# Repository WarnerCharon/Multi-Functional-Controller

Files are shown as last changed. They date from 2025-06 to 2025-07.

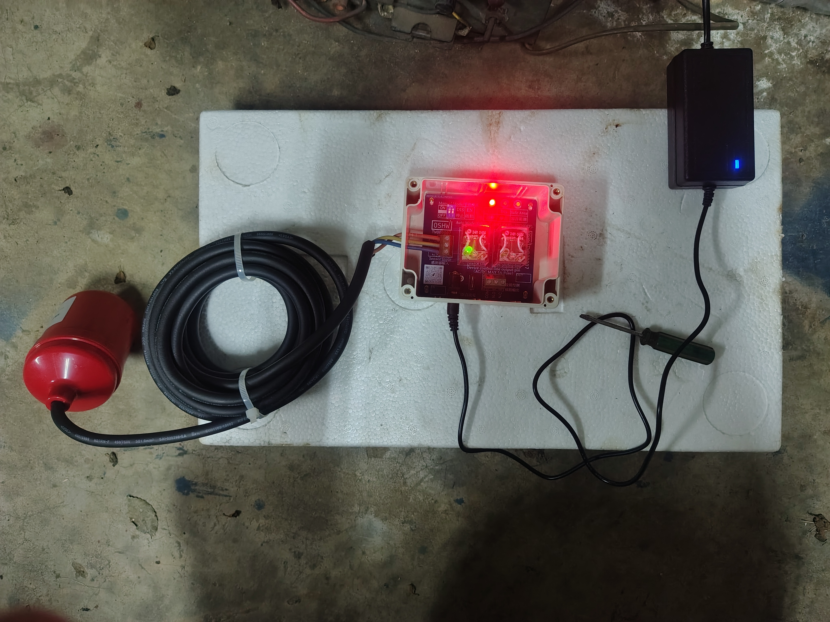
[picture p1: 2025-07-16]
Technical Documents/展示圖_2.jpg

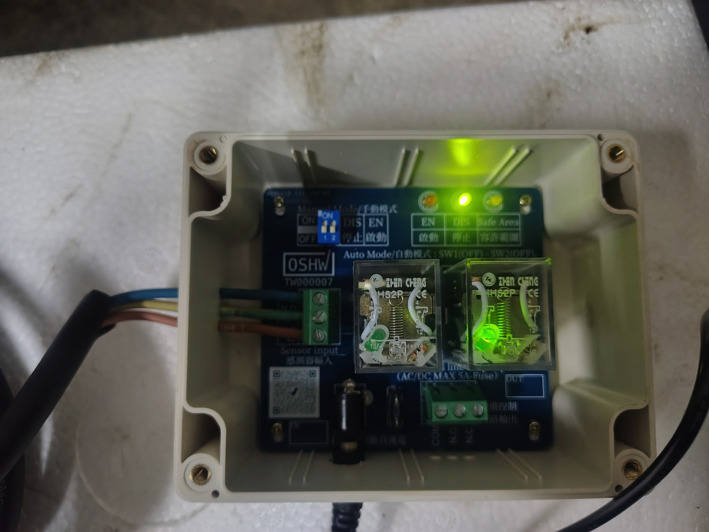
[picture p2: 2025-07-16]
Technical Documents/展示圖_1.jpg

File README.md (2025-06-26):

certification-mark-TW000007-stacked

EN:
The Multi-Functional-Controller is an open-source industrial-grade mechanical logic controller designed to handle multiple control scenarios such as liquid level regulation, pneumatic pressure stabilization, and temperature management. It utilizes reliable mechanical relay logic and discrete input signals to achieve three-point control: Start, Maintain, and Stop — enabling stable and efficient actuation of pumps, compressors, heaters, and fans. The controller incorporates built-in anti-chatter logic to prevent unnecessary rapid switching caused by signal fluctuations, thereby extending equipment life.

Designed for plug-and-play operation, the controller requires no software programming, making installation and commissioning simple for industrial operators. Control setpoints are defined via external sensors or float switches wired directly to its input terminals. The output controls motorized equipment directly, supporting both single-phase and three-phase loads. An intuitive LED status display provides real-time visual feedback of the system state.

The open hardware release includes complete schematics, PCB layouts, electrical assembly diagram, detailed component BOM, and connection diagrams. The operation logic are fully documented and provided under open-source licenses. Users can freely build, modify, adapt, and integrate the design into custom automation solutions.

This controller is ideal for industrial water treatment systems, HVAC units, air compressors, and process control where reliable, simple, and low-cost control is needed without the complexity of PLC programming. Its open-source nature allows educational institutions, OEM manufacturers, system integrators, and hobbyists to adopt, learn, and further develop derivative control systems while contributing back to the open hardware community.

This controller project (Multi-Functional-Controller) fully complies with international open source hardware standards and is officially certified by the Open Source Hardware Association (OSHWA). All design archives and source codes are released under the following licenses:

Hardware design: OSHWA、CERN OHL-W v2.0

Control logic: Apache License 2.0

Document content: CC-BY 4.0

OSHWA Certification ID: TW000007
https://certification.oshwa.org/tw000007.html

👉 GitHub original code and design access: https://github.com/WarnerCharon/Multi-Functional-Controller

Multi-Functional-Controller  © 2025/6 by TSAI, AN-HSIANG is licensed under CC BY 4.0. To view a copy of this license, visit https://creativecommons.org/licenses/by/4.0/

TW:
多功能控制器是一種開源工業級機械邏輯控制器，旨在處理多種控制場景，例如液位水平調節，氣動壓力穩定和溫度管理。它利用可靠的機械繼電器邏輯和離散輸入信號來實現三點控制：啟動，維護和停止 - 可以穩定，有效地致動泵，壓縮機，加熱器和風扇。控制器結合了內置的反塊狀邏輯，以防止信號波動引起的不必要的快速切換，從而延長設備壽命。

該控制器專為插件操作而設計，不需要軟件編程，使工業運營商的安裝和調試簡單。控制設定點是通過外部傳感器或直接連接到其輸入終端的浮子開關來定義的。輸出直接控制電動設備，支持單相和三相載荷。直觀的LED狀態顯示提供了系統狀態的實時視覺反饋。

開放的硬件版本包括完整的原理圖，PCB佈局，電氣組件圖，詳細的組件BOM和連接圖。操作邏輯已完全記錄並在開源許可下提供。用戶可以自由構建，修改，適應和集成設計到自定義自動化解決方案中。

該控制器非常適合工業水處理系統，HVAC單元，空氣壓縮機以及過程控制，而在沒有PLC編程的複雜性的情況下，需要可靠，簡單和低成本的控制。它的開源性質允許教育機構，OEM製造商，系統集成商和業餘愛好者採用，學習和進一步開發衍生性控制系統，同時又回到開放的硬件社區。

本控制器專案（Multi-Functional-Controller）完全符合國際開源硬體標準，並獲得開源硬體協會（OSHWA）的官方認證。所有設計檔案和原始碼均遵循以下許可證發布：

硬體設計：OSHWA、CERN OHL-W v2.0

控制邏輯：Apache License 2.0

文檔內容：CC-BY 4.0

OSHWA Certification ID: TW000007
https://certification.oshwa.org/tw000007.html

👉 GitHub 原始碼與設計存取：https://github.com/WarnerCharon/Multi-Functional-Controller

Multi-Functional-Controller  © 2025/6 by TSAI, AN-HSIANG is licensed under CC BY 4.0. To view a copy of this license, visit https://creativecommons.org/licenses/by/4.0/

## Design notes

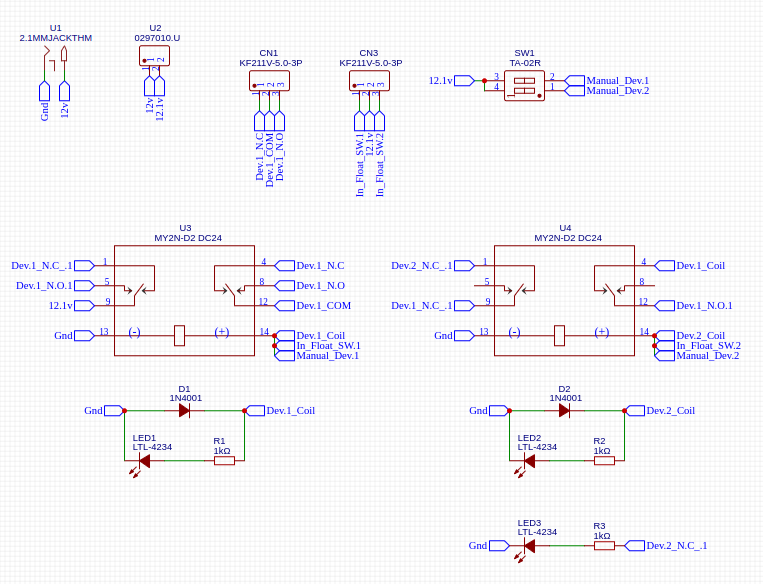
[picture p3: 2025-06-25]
hardware/Schematic.png

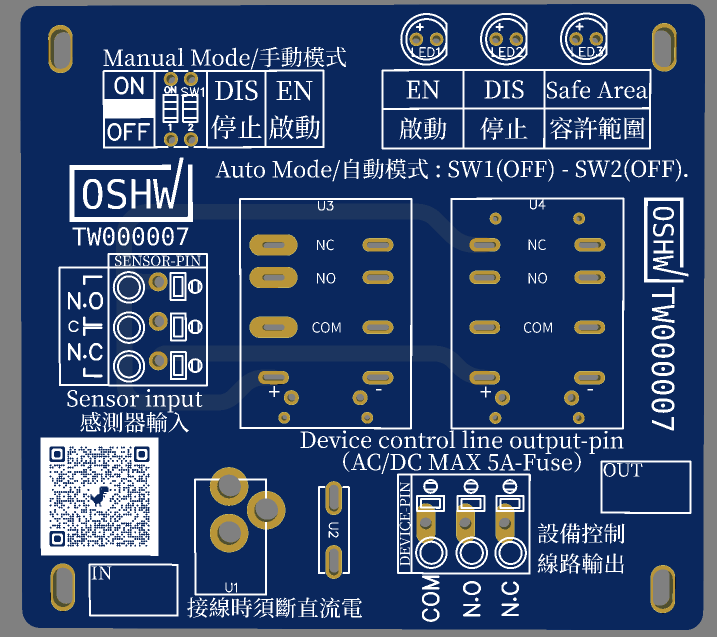
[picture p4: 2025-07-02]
Technical Documents/Photo/3D/top_n.png

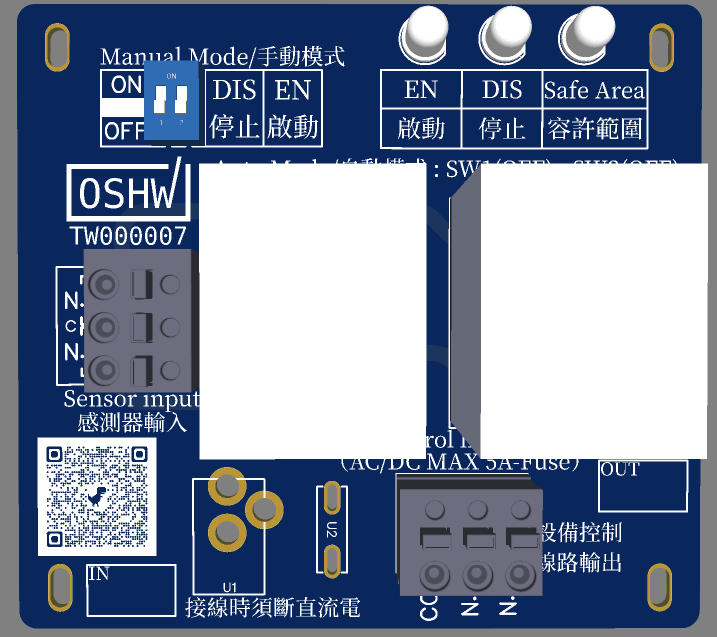
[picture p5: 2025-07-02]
Technical Documents/Photo/3D/top.png

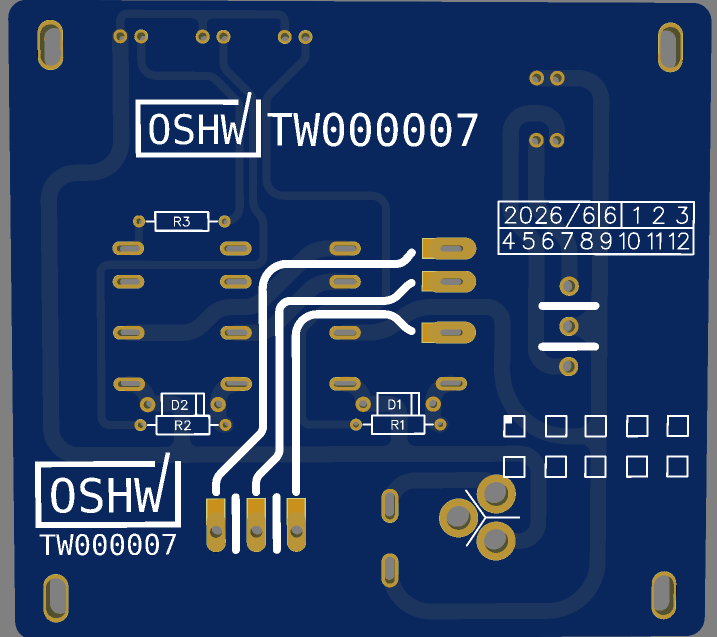
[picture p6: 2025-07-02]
Technical Documents/Photo/3D/button.png

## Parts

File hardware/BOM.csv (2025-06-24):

ID | Name | Designator | Footprint | Quantity
1 | 1N4001 | D1,D2 | DO-41_BD2.4-L4.7-P8.70-D0.9-RD | 2
2 | 1kΩ | R1,R2,R3 | RES-TH_BD2.3-L6.5-P10.50-D0.5 | 3
3 | KF211V-5.0-3P | DEVICE-PIN,SENSOR-PIN | CONN-TH_3P-P5.00_KF211V-5.0-3P | 2
4 | LTL-4234 | LED1,LED2,LED3 | LED-TH_BD5.0-P2.54-FD | 3
5 | TA-02R | SW1 | SW-TH_TA-02R | 1
6 | 2.1MMJACKTHM | U1 | PJ-102A | 1
7 | 0297010.U | U2 | FUSE-TH_0297010.WXNV | 1
8 | MY2N-D2 DC24 | U3,U4 | RELAY-TH_OMRON-MY2 | 2

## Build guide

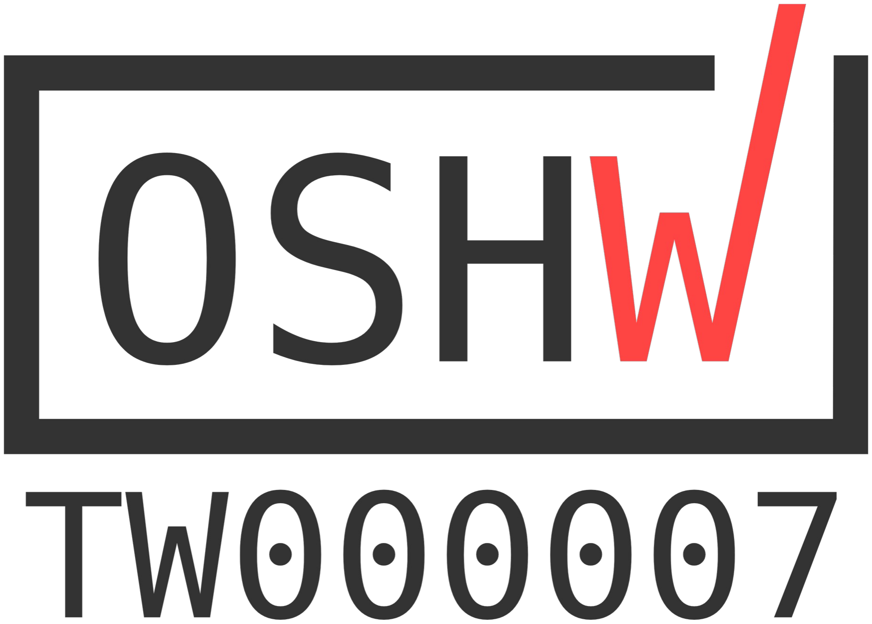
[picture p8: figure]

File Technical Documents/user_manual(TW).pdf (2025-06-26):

目次

TW000007

# 1. 產品概述

## 核心功能

- 高靈活性多功能控制器，採用機械接點設計，無電子故障風險，避免頻繁啟停，延長設備壽命， 適用於液體、氣體、溫度等多種物理量的控制。
- 成本效益高、免編程、安裝簡單，模組化設計使平均維修工時縮短 40%。
- 性價比高，適合中小型工程場域。

## 主要特色

- 三段式精確控制：啟動/停止/容許範圍邏輯
- 雙重操作模式：自動/手動切換
- 機械抖動消除技術：防止頻繁啟停
- 直觀狀態指示：LED 燈號顯示
- 工業級 PCB 材料：主控板採用 FR4 玻璃纖維基板，具備優異的耐腐蝕、耐高溫性能， 適用於嚴苛工業環境，提升產品壽命與安全性

## 典型應用

應用類型 | 控制對象 | 典型場景
液位控制 | 水泵、排水泵 | 水塔補水、污水處理
氣壓控制 | 空壓機、氣動系統 | 工廠供氣、氣動設備
溫度控制 | 加熱器、冷卻風扇 | 設備散熱、環境溫控

# 2. 安全須知

## ⚠️安裝前必讀

電氣安全
- 所有電氣作業必須在斷電狀態下進行
- 控制板輸入電壓規格（12V）
- 確認現場電壓符合設備規格（110V/220V AC）
- 必須安裝適當的接地保護
- 使用正確規格的保險絲（5A）
機械安全
- 避免感測器受到直接衝擊或振動
- 預留足夠的維護空間

環境要求

- 工作溫度：-10°C ~ 50°C
- 避免直接日曬、雨淋
- 遠離腐蝕性氣體環境

# 3. 技術規格

## 基本規格

項目 | 規格 | 備註
電源電壓 | 110V/220V AC ±10% 根據型號選擇
保險絲 | 5A | 兩種電壓通用
輸出通道 | 1 組獨立控制輸出 | 可控制單相/三相馬達
感測輸入 | 3 點式接點輸入 | N.O/N.C/COM
工作溫度 | -10°C ~ 50°C | 工業級元件
防護等級 | IP54 | 防塵防水濺
外形尺寸 | 240×180×95mm | 壁掛式安裝

## 輸入訊號特性 ＊

訊號穩定性要求 ＊
- 所有輸入皆為「接點觸發」，若輸入訊號波動過快（如氣壓快速變化），建議：
- 加裝繼電器延遲模組
- 增加濾波/去抖時間設定
- 確保感測器機構反應靈敏且無接觸不良
三段區間辨識清晰度 ＊
- 三點控制需有明確的「高／中／低」輸出狀態
- 若只有雙段訊號，將導致容許範圍判斷失效
- 若僅一段訊號（如單段限位），則無法達成本控制邏輯，建議改用其他控制器

## 術語定義

術語 | 英文縮寫 | 定義
常開接點 | N.O | 平時斷開，觸發時閉合
常閉接點 | N.C | 平時閉合，觸發時斷開
共同點 | COM | 接點共用端子
過載保護 | OL | 馬達過載保護裝置
繼電器 | KM1/KM2 | 控制馬達的繼電器模塊

# 4. 安裝指南

## 4.1 安裝準備

環境檢查清單
- 電源電壓確認（110V/220V）
- 安裝空間評估（預留維護空間）
- 環境條件檢查（溫度、濕度、腐蝕性）
工具準備
- 螺絲起子、數位電錶、絕緣膠帶
- 配線管材、接線端子、標籤紙

## 4.2 機械安裝 ＊

控制器安裝
1. 選擇乾燥、通風良好的位置
2. 使用 DIN 導軌或螺絲固定
3. 確保防護等級符合現場環境
感測器安裝
1. 液位感測器
- 安裝高度：距離液面 0.5-1.5 公尺
- 避免水流直接衝擊
- 確保浮球動作範圍無阻礙
2. 其他感測器
- 確保感測範圍無遮擋物
- 避免機械振動干擾
- 考慮環境與溫度影響

機構安裝與回復機制 使用於移動、限位、轉速等應用時，建議：
- 感測器安裝處需避開干擾源與機械擾動 ＊＊
- 感測件應能「自復原狀態」（如彈簧回復、磁性歸位） ＊＊

## 4.3 電氣接線

基本接線步驟
1. 斷電確認：確保所有電源已切斷
2. 主電源接線：L1、L2 端子接入 AC 電源
3. 感測器接線：按照 N.O、N.C、COM 標示接線
4. 負載接線：連接執行機構（馬達、泵浦等）- > (附錄 A. 感測器控制接線圖)
5. 保護接線：連接過載保護器和接地線
接線規範
- 線徑選擇：根據負載電流選擇適當線徑
- 接線牢固：確保端子螺絲緊固
- 標識清楚：所有線路必須標識
- 絕緣良好：接線完成後進行絕緣測試

## 4.4 測試驗證

系統檢查
1. 電源測試
- 控制班輸入電壓：12V
- 測量輸入電壓：110V/220V ±10%
- 確認保險絲規格正確
- 檢查指示燈是否正常點亮
2. 感測器測試
- 手動觸發感測器
- 觀察指示燈變化
- 測量接點阻抗
3. 執行機構測試
- 手動模式測試馬達動作
- 檢查過載保護功能
- 確認控制邏輯正確

# 5. 操作與應用

## 5.1 控制面板說明

指示燈狀態
指示燈 1 紅色 觸發動作（系統啟動）
指示燈 2 綠色 停止狀態（系統停止）
指示燈 3 黃色 容許範圍（正常等待）

手動操作開關

SW1 ON 系統停止
SW2 ON 手動強制啟動

## 5.2 操作模式

自動控制模式

- SW1 & SW2 設為 OFF
- 系統依感測器狀態自動運行
- 適用於正常運行狀態
手動控制模式
- SW1 設為 ON：強制停止
- SW2 設為 ON：強制啟動
- 適用於測試或緊急情況
混合控制模式
- 正常時自動控制
- 必要時手動介入
- 適用於需要彈性操作的場合

## 5.3 基本應用

液位控制系統
應用場景：家用、工業、循環用水、地下室排水、排污、清洗用水、綠化澆灌，等等…。 進水控制：低水位啟動→中水位（正常容許範圍）→高水位停止 排水控制：高水位啟動→中水位（正常容許範圍）→低水位停止

應用設定
功能 觸發接點 停止接點 共同點
進水 N.C | N.O | COM
排水 N.O | N.C | COM

## 5.4 延伸應用

氣壓控制系統
- 應用場景：空壓機、氣動設備壓力控制 、工廠供氣系統、儲氣桶壓力管理
- 控制對象：螺旋式空壓機(15HP)、工業用空壓機
- 感測要求：三段式壓力開關
溫度控制系統
- 控制對象：加熱器、冷卻風扇
- 感測要求：三段式溫控開關
- 控制邏輯：低溫啟動→適溫維持→高溫停止
特殊控制應用
- 高度/距離控制：需配合信號轉換器
- 轉速控制：適用於低精度間接控制
- 流量控制：需配合流量開關

# 6. 參數設定

## 6.1 物理量特性評估 ＆ 參數設定指南

參數調整可依現場情況優化，若動作過頻可擴大遲滯區間或增加抖動消除時間，若反應遲緩則反向調整。 響應時間分類
類型 | 變化時間 | 典型應用(須根據場景)
快速響應 | <5 秒 | 氣壓、液壓系統
中等響應 | 5-30 秒 | 小容量液位控制
慢速響應 | >30 秒 | 溫度、大容量液位

抖動消除時間設定（如有加裝繼電器延遲模組 ）
可根據應用類型（液位、氣壓、溫度、位置）調整抖動消除時間（如 2-60 秒），防止訊號雜訊造成頻繁 切換。
應用類型 | 建議時間 | 設定原則
液位控制 | 2-5 秒 | 根據液體流動速度
氣壓控制 | 3-8 秒 | 考慮氣體壓縮特性
溫度控制 | 30-60 秒 | 依據熱慣性調整

遲滯區間設定（如有加裝繼電器延遲模組 ）
可設定容許範圍（遲滯區間），如液位控制可設 0.5-1.5m、氣壓 0.5-2bar 等，避免物理量在臨界點反覆 切換。
應用類型 | 建議區間 | 計算方式
液位 | 0.5-1.5m | 容器高度×(3-8%)
氣壓 | 0.5-2bar | 最大壓力×(5-10%)
溫度 | 2-10°C | 控制範圍×(3-8%)

## 6.2 優化流程

步驟 1：初始設定 根據應用類型選擇建議參數，以保守值開始 步驟 2：運行測試
連續運行 24-48 小時，記錄：
- 控制動作頻率
- 物理量變化範圍
- 異常觸發次數
步驟 3：參數調整
- 動作過頻：增加抖動時間或擴大遲滯區間
- 反應遲緩：減少抖動時間或縮小遲滯區間
- 偶發誤動：檢查干擾源，增加濾波措施
步驟 4：最終驗證 調整後再次測試，確認系統穩定性

# 7. 維護與故障排除

## 7.1 定期維護

每月檢查

- 清潔設備外殼 | • 檢查指示燈狀態 | • 測試手動操作功能
- 檢查接線端子 | • 記錄運行狀態

每季檢查

- 清潔感測器 | • 檢查感測器動作 | • 測量絕緣阻抗
- 檢查執行機構 | • 校正控制參數

每年檢查

- 全面系統檢查 | • 更換易損零件 | • 校正感測器
- 更新運行記錄 | • 評估系統性能

## 7.2 故障診斷

快速診斷表
故障現象 | 可能原因 | 檢查重點 | 解決方法
完全無反應 | 電源故障 | 電壓、保險絲 | 修復電源、更換保險絲
指示燈不亮 | 控制板故障 | 控制板電源 | 更換控制板
頻繁啟停 | 參數不當 | 抖動時間、遲滯區間 | 調整控制參數
不會自動啟動 | | 感測器故障 | 感測器接線、動作 | | 修復或更換感測器
無法停止 | | 執行機構故障 | 接觸器、馬達 | | 檢修執行機構

診斷流程
系統故障 → 電源正常？ → 指示燈正常？ → 感測器動作？ → 執行機構動作？ → 控制邏輯正確？
↓ | ↓ | ↓ | ↓ | ↓ | ↓
檢查電源 檢查控制板 檢查感測器 檢查執行機構 | 檢查參數設定 | 系統正常

## 7.3 常見問題解答

Q1：系統頻繁啟停如何處理？
A：診斷步驟
1. 檢查感測器安裝位置是否受擾動影響 | 2. 增加抖動消除時間
3. 擴大遲滯控制區間 | 4. 檢查感測器是否有接觸不良

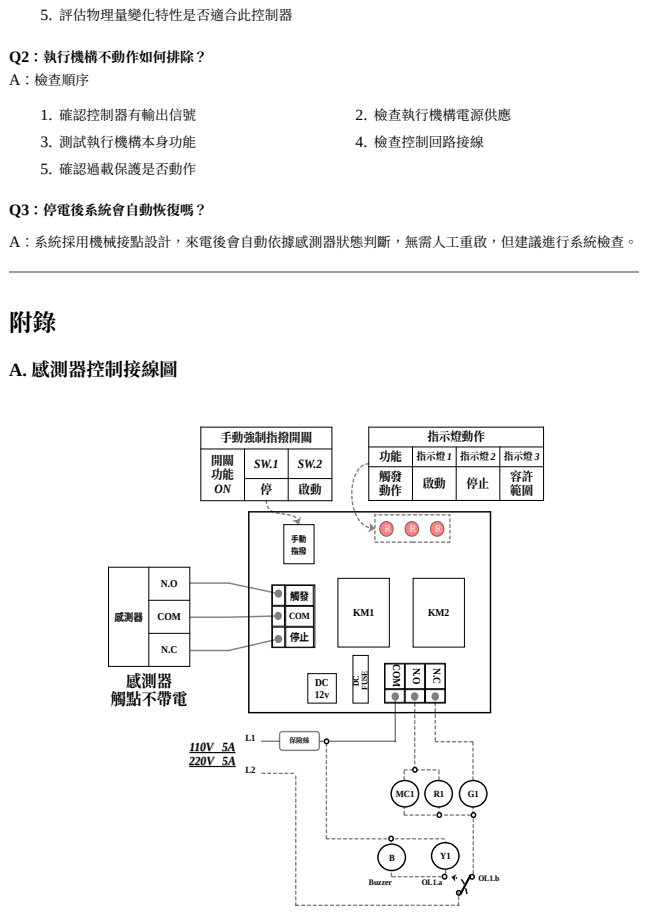
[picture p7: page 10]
5. 評估物理量變化特性是否適合此控制器; Q2：執行機構不動作如何排除？ A：檢查順序; 1. 確認控制器有輸出信號; 2. 檢查執行機構電源供應; 3. 測試執行機構本身功能; 4. 檢查控制回路接線; 5. 確認過載保護是否動作; A. 感測器控制接線圖; FUSE; 手動強制指撥開關 開關 功能 ON; 指示燈動作; 指示燈 1; 指示燈 2; 指示燈 3; 保險絲 110V 5A 220V 5A; 感測器; COM; N.C 感測器 觸點不帶電; Buzzer

Q3：停電後系統會自動恢復嗎？
A：系統採用機械接點設計，來電後會自動依據感測器狀態判斷，無需人工重啟，但建議進行系統檢查。

COM
停止

## B. 控制時序說明 ＆ 控制邏輯

- 當感測器偵測到「低」狀態，控制器啟動執行機構（如馬達、泵浦）。
- 當物理量進入「中」區間，進入容許範圍，執行機構保持現狀（不啟動也不停止）。
- 當感測器偵測到「高」狀態，控制器發出停止指令，執行機構停止動作。

文件資訊
- 文件版本：V1.0
- 發布日期：2025 年 6 月
- 文件編號：Multi-Functional-Controller-V1.0

Multi-Functional-Controller © 2025/6 by TSAI, AN-HSIANG is licensed under CC BY 4.0.

### To view a copy of this license, visit https://creativecommons.org/licenses/by/4.0/

本控制器為通過國際開源硬體協會（OSHWA）認證之開源硬體專案。 專案名稱：Multi-Functional-Controller
認證編號：[TW000007]

機械響應＋觸發啟動運作時間

感測器 N.O

感測器 N.C

控制器 N.O

控制器 N.C

消除抖動 | 消除抖動

停止運作時間
